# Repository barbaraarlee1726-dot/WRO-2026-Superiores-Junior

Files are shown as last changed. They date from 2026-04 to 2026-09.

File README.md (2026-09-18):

WRO-2026-FUTURE ENGINEERS
---------------------------
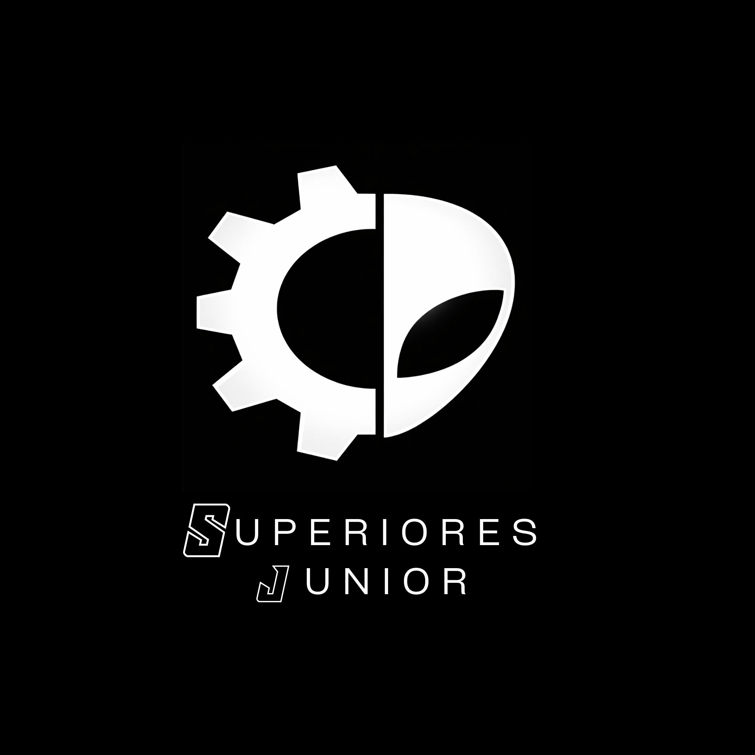
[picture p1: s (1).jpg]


This document describes the complete design and implementation of an autonomous vehicle built to compete in the World Robot Olympiad (WRO) 2026 under the Future Engineers category. Our robot integrates computer vision, gyroscopic navigation, ultrasonic sensing, and custom PCB design to achieve reliable autonomous operation.
The WRO Future Engineers category challenges teams to design a vehicle capable of operating without any human intervention, adapting dynamically to track conditions and obstacles. The competition is divided into two main challenges: Open Challenge and Obstacle Challenge.

--------------

We are the Junior Superiors team, and we are one of the teams that will be participating in the 2026 WRO (World Robot Olympiad) Future Engineers category.

What is the WRO?

The WRO is a competition that, as its name suggests, is a global competition. We are participating in the Future Engineers category, which focuses on autonomous cars. We have developed our robot named Timmy, an autonomous car whose goal is to navigate two different tracks presented in the competition: the Open Challenge and the Obstacle Challenge. The Open Challenge is an open track without obstacles that we must complete in the shortest time possible; the faster we go, the more points we earn. The Obstacle Challenge uses the same track but with different obstacles. In the Obstacle Challenge, there are two pillars of two different colors that we must navigate without colliding with them; the red pillar means turning right, while the green pillar means turning left. Timmy must navigate all these obstacles without hitting the walls or pillars.

Our robot was designed as a single-piece unit; we did this to minimize the number of parts and make it simple to build. Since the robot is a single piece, it uses a traction system to support the robot’s entire weight because, being very large, it is quite heavy, which makes it difficult to reach high speeds. To solve this problem, we integrated a traction system so that with a single motor we can achieve a decent speed. We use a parallel steering system; its main advantages are saving space, having a greater advantage in turns because it provides better handling at high speeds, and reducing lateral wheel slip.
This is the process of building our robot, and here’s how it went: We started building the robot’s first base on the very first day. Since it was the first day, we were only able to build a small base for both the front and rear wheels; with the limited time we had that day, we only managed to build that small base, which  would serve as a reference for the entire robot. From there, we began experimenting; for example, the next thing we built was the steering mechanism with a design that was easy to turn,  or the servomotor, which was placed on the bottom to save space. We installed a steering system so that, with a single motor, the steering and the other motors could operate simultaneously. Then we expanded the robot a bit to make more room for the next components. Since the top was a bit uneven, we created a platform where we could work more easily. We reinforced all the components, added ultrasonic sensors to the sides of the robot to modify them later, created the platform for the HuskyLens, and mounted the board, then reinforced everything again with screws. You can review everything we just mentioned in the blog, journal (in the “Others” section), and in the documentation section.

The code we use is actually quite simple: we program the Husky Leens camera using Arduino via the PCB. The camera detects the colors of the pillars for the Obstacle Challenge category; if HuskyLeens detects a red pillar, it turns right; if it detects a green pillar, it turns left; so our robot knows which way to turn. The ultrasonic sensors are used for both categories (Open Challenge and Obstacle Challenge); they detect the black walls, so when they detect them at a certain close distance, the robot will turn to avoid colliding. We programmed everything using the board and an Arduino Uno; you can check out the code in src.

Initial tests: We started on the first OpenChallenge track, so our programming for it went something like this: we programmed the ultrasonic sensors so that at a specific distance, the robot would turn in the opposite direction.  in the first tests we got decent results; the robot veered off course a bit, but we calibrated it. It was slow, so we adjusted the speed and also the rotation so that the increased speed wouldn’t cause it to crash. We also had trouble calculating when to stop so that it would be on the exact line or remain in the parking spot. After some trial and error, we came up with a program that worked well for us, and all that was left was to improve it. However, when we did that, it started to malfunction a bit, so we calibrated both the components and the program to fix it. For the Obstacle Challenge, since it was already very late, we didn’t have time to create a highly efficient program, though it still turned out to be effective. The program was simple: if the HuskyLens detected the red pillar, it turned left; if it detected a green one, it turned left. Finally, we reduced the speed and the turning radius so it wouldn’t collide with the pillars (you can review the entire program in the src section).

The components we use for our robot (Timmy) are essential because they essentially serve as the robot’s legs and eyes. Our chassis design creates adequate spaces for each component so that they complement one another. The EV3 motor (located at the bottom) provides power and saves space thanks to the strategic positioning of each component. Additionally, on the bottom, aside from the motor, is the traction system designed to boost the wheels’ speed, in addition to another system we have for the wheels. Finally, also on the bottom is the steering system, which, as we’ve already mentioned, is effective and precise. Moving to the top of the robot, we have the actual electronic components. To start with, there is the heart of Timmy, the PCB, which essentially handles all the programming—including that of the motor and steering—at the same time, despite being a LEGO build. on either side of the board are several ultrasonic sensors that help prevent collisions with walls. The HuskyLens camera with the AI system is very useful since it saves us a lot of programming work and detects the different pillars very well. Our main problem was all the dead space we left due to a construction issue—the top wasn’t very level, so we added several pieces to make it somewhat flat and improve maneuverability. All that dead space we left meant we lost the space we were trying to save (dead space is unused space).

In conclusion, our robot features a stable, durable, and powerful design, capable of meeting the challenges it faces. It uses simple yet effective programming. In my opinion, our main goal is to inspire new people interested in robotics so they can have a good time while discovering new things.

Category: Future Engineers

Team Name: Superiores Junior

Location: Nuevo León, México

## TEAM PHOTO
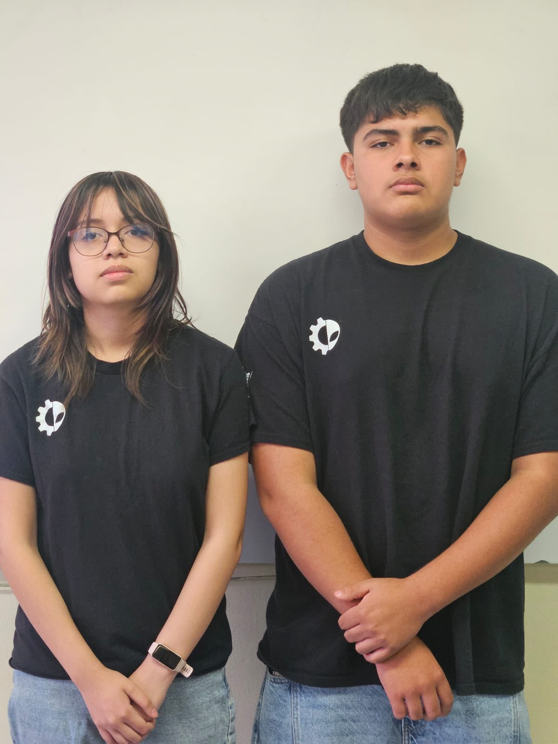
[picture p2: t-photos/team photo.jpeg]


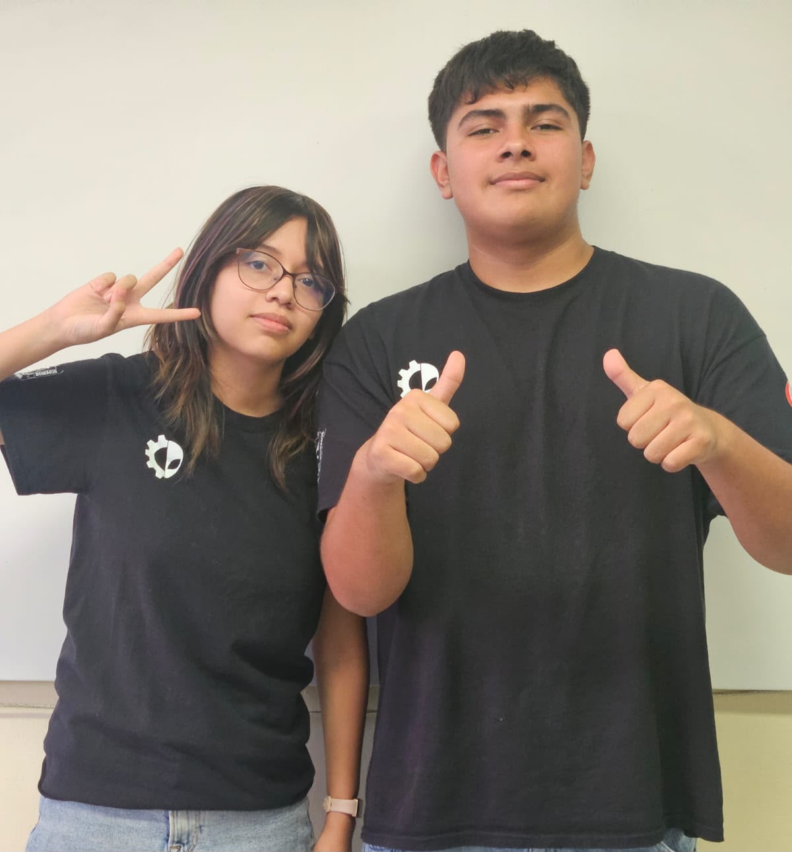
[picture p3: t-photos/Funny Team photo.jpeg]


TEAM MEMBERS
---------
Leadership & Coaching
Coach: Eduardo Alvarado González (40 years old)

<div align="center">
Eduardo Gonzalez
</div>

Role: Strategic Mentor and Founder. 
Eduardo is an engineer and professor who founded "Los Grises Superiores" in 2014. His vision has guided multiple generations of students to succeed in national and international robotics competitions, building a culture of technical excellence, teamwork, and resilience. He provides strategic direction and ensures all engineering decisions align with competition requirements.

---------------------------

Bárbara Arlee Flores Marroquín (15 years old)

Role: Captain and Electronics Lead.

Age:15

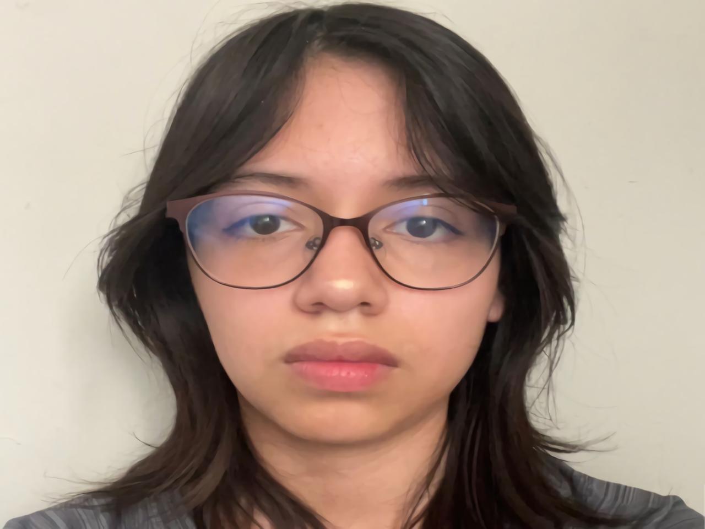
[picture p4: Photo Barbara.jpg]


"I got started in robotics in my sophomore year of high school, having been selected for my strong academic performance and adaptability, as well as my interest in challenges and complex designs, and I received a diploma for my achievements.I have honed my skills by taking additional robotics courses at this institution, where, in addition to learning, I received a certificate of completion."

Bárbara joined robotics in her sophomore year of high school, having been selected for her strong academic performance and interest in complex engineering challenges. She earned a diploma for her achievements and has since completed additional robotics certifications. In this project, she is responsible for electronic design, PCB development, and system integration.

---------------------------

Arath Alejandro Reyna Granados

Age:15

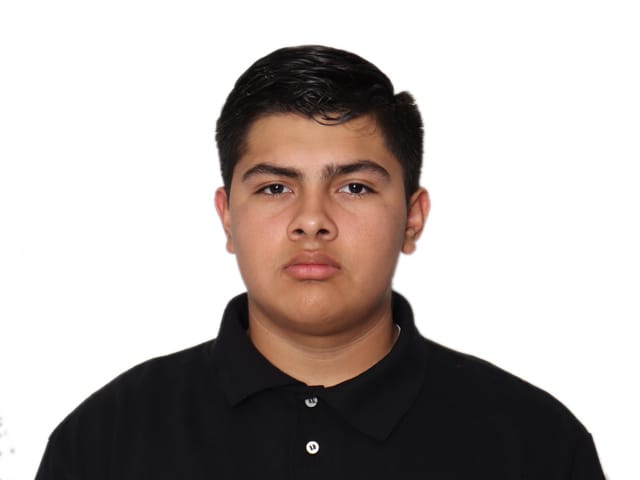
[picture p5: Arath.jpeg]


Role:Lead Programmer.

"I started in robotics at age 13 thanks to my mom, who started a robotics course at my school. There, I was told about a summer course offered by the Normal Superior of Nuevo León, Mexico, where I learned many things. After the course ended, a few months passed, and we were invited back. I was selected to compete in WRO."

Arath began his robotics journey at age 13 after participating in a course at the Normal Superior de Nuevo León, Mexico. He was subsequently selected to compete in WRO due to his aptitude and dedication. He is responsible for all firmware development, including the navigation algorithms, sensor fusion logic, and obstacle avoidance routines implemented on the Arduino Nano.

---------------------------

## 📚 Contents
- [Project Overview](#project-overview)
- [Vehicle Photos](#vehicle-photos)
- [Components and Hardware](#components-and-hardware)
- [Mobility Management](#mobility-management)
  - [Chassis](#chassis)
  - [Steering System](#steering-system)
- [Documentation](#Documentation)
- [Power and Sense Management](#power-and-sense-management)
  - [Power Management](#power-management)
  - [Sense Management](#sense-management)
- [Obstacle Management](#obstacle-management)
- [WRO 2026 Competition Info](#wro-2026-competition-info)
  
## Project overview

This document describes the design and implementation of an autonomous vehicle built to compete in the World Robot Olympiad 2026, under the category known as Future Engineers. This competition requires teams to conceive, assemble, and program a vehicle capable of operating without human intervention, adapting to different environmental conditions and established rules.
The Future Engineers category is divided into two challenges:

Open Challenge:

The vehicle must complete exactly three laps on a fixed-layout track. The direction of travel (clockwise or counterclockwise) and the starting position are determined randomly at the start of each run. This requires a navigation system that relies entirely on real-time sensor data rather than pre-programmed routes. Our system uses two HC-SR04 ultrasonic sensors to measure wall distances and an MPU6050 gyroscope to count rotations and determine lap completion.

Obstacle Challenge:

The Obstacle Challenge follows the same lap dynamics as the Open Challenge but adds colored pillars that act as traffic signals. The robot must detect and respond to each pillar in real time:

•	Red pillar → the vehicle must pass to the right of the obstacle

•	Green pillar → the vehicle must pass to the left of the obstacle

The HuskyLens AI camera handles color recognition and calculates the X-position of each detected object, allowing the servo steering system to compute the correct avoidance trajectory dynamically.

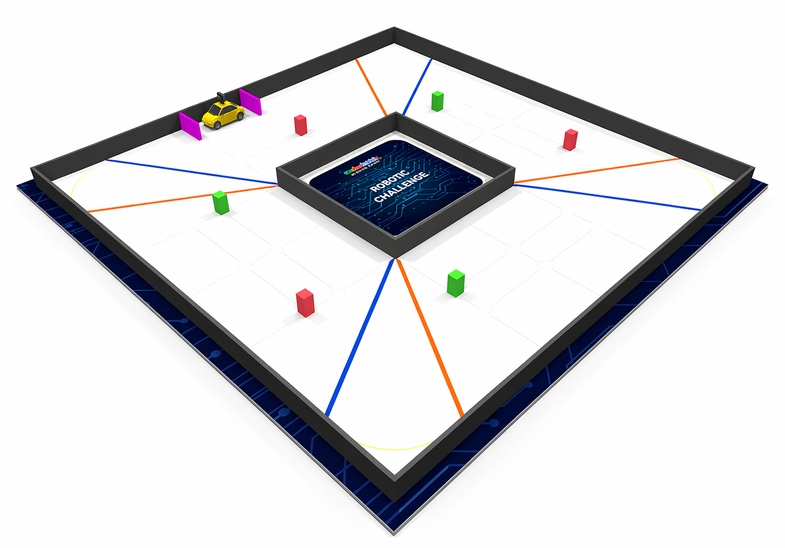
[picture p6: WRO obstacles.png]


# Vehicle Photos

<div align="center">

| Front | Back |
|:--:|:--:|
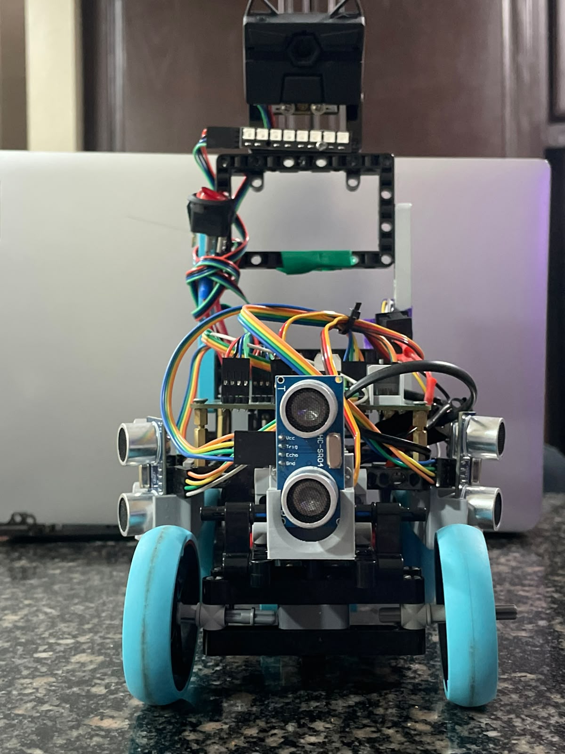
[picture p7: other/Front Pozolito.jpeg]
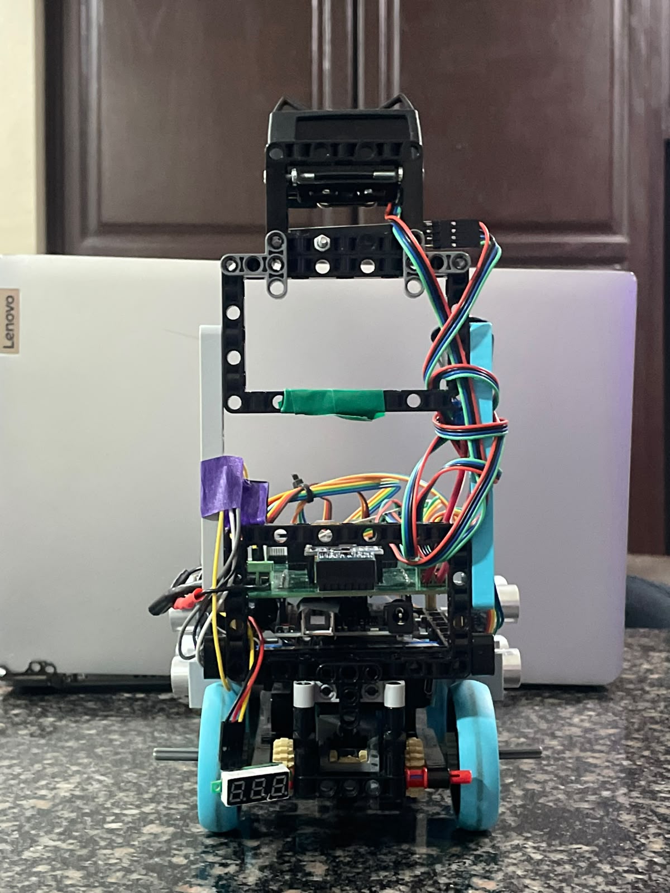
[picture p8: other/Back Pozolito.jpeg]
|  | |

| Bottom | Top |
|:--:|:--:|
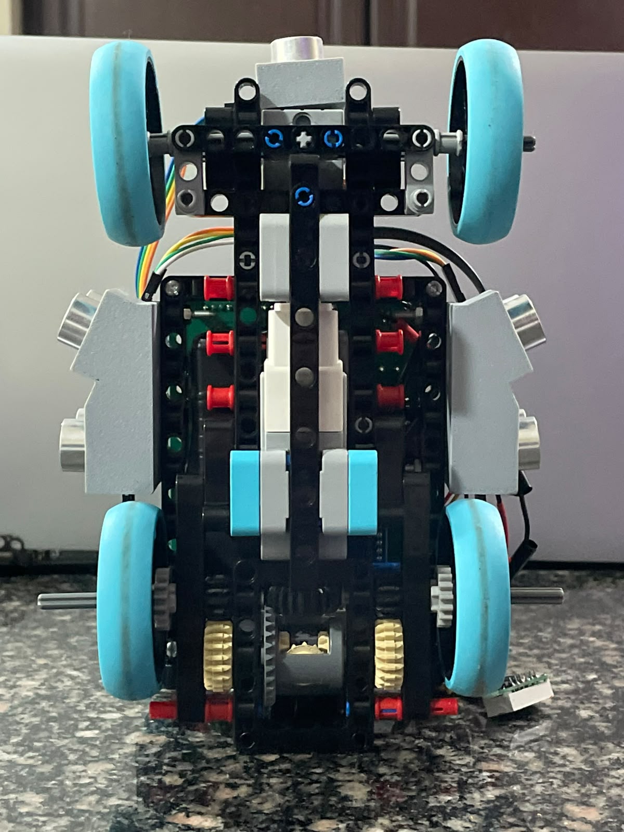
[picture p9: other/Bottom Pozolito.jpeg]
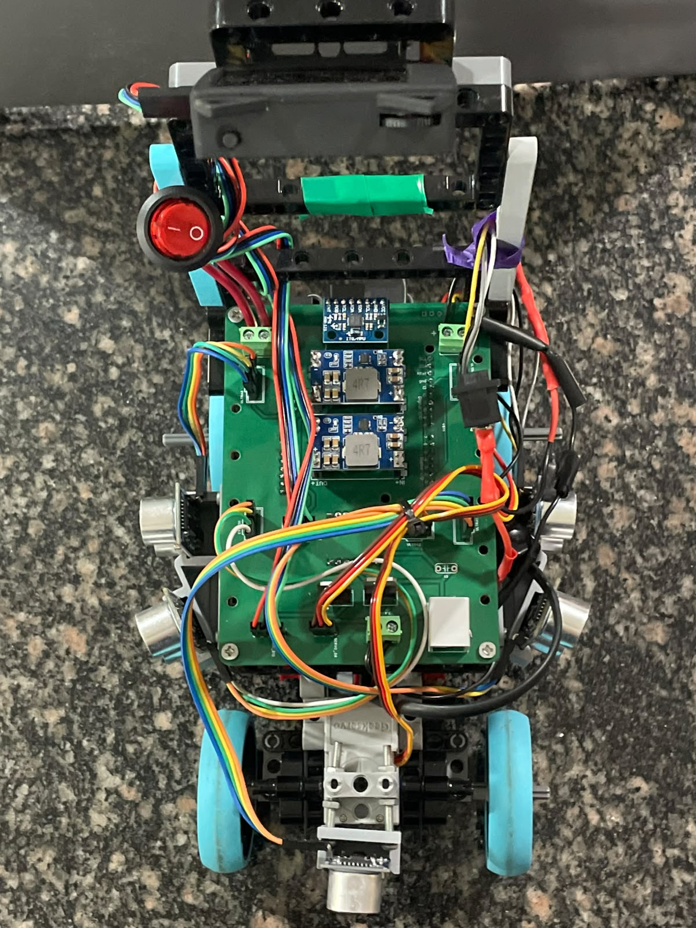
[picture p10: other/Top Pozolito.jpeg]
|  |    |

| Left | Right |
|:--:|:--:|
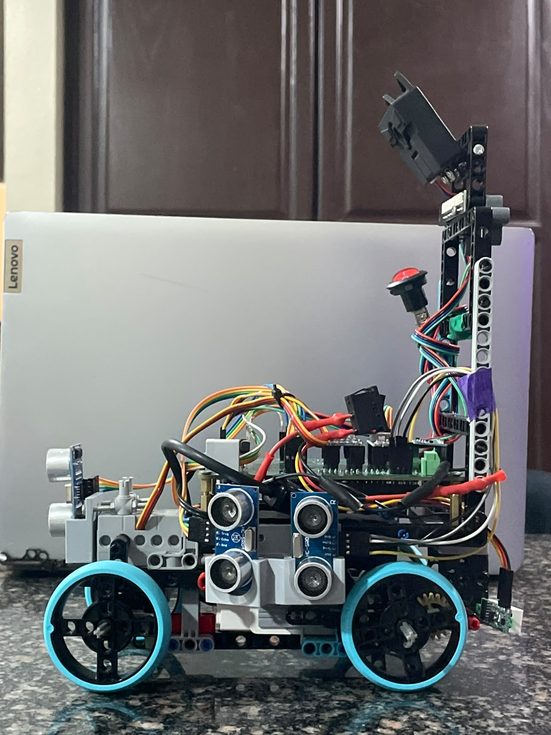
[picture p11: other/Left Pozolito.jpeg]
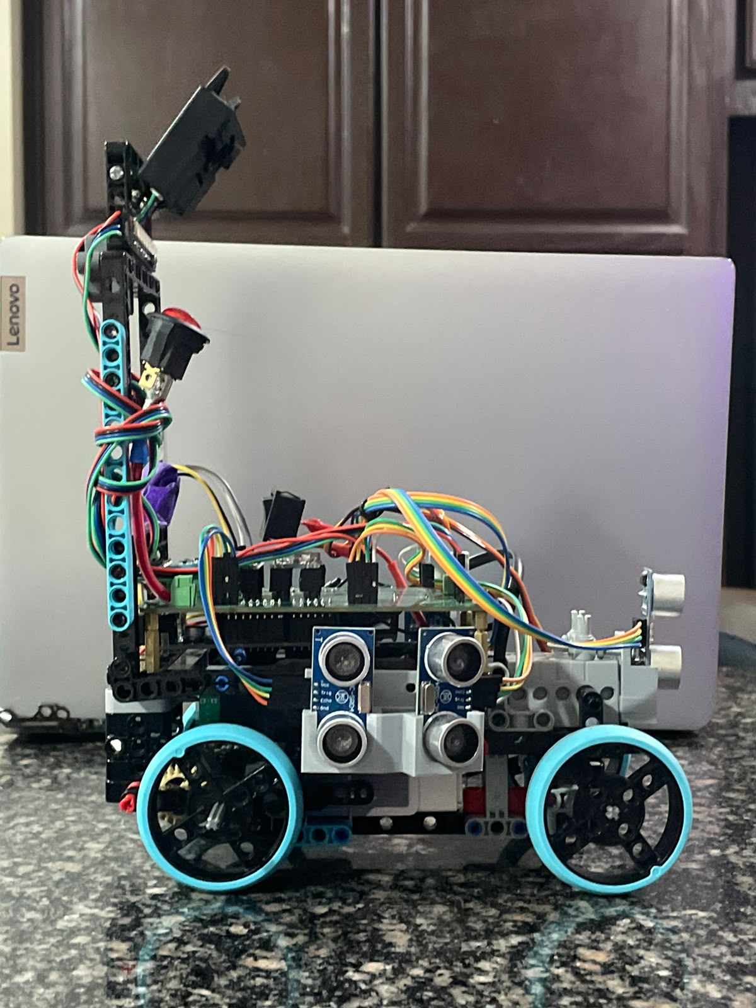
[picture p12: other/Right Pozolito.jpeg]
|   | |

## Components and Hardware

|COMPONENT| DESCRIPTION | IMAGE | PURCHASE LINK|
|---|---|---|---|
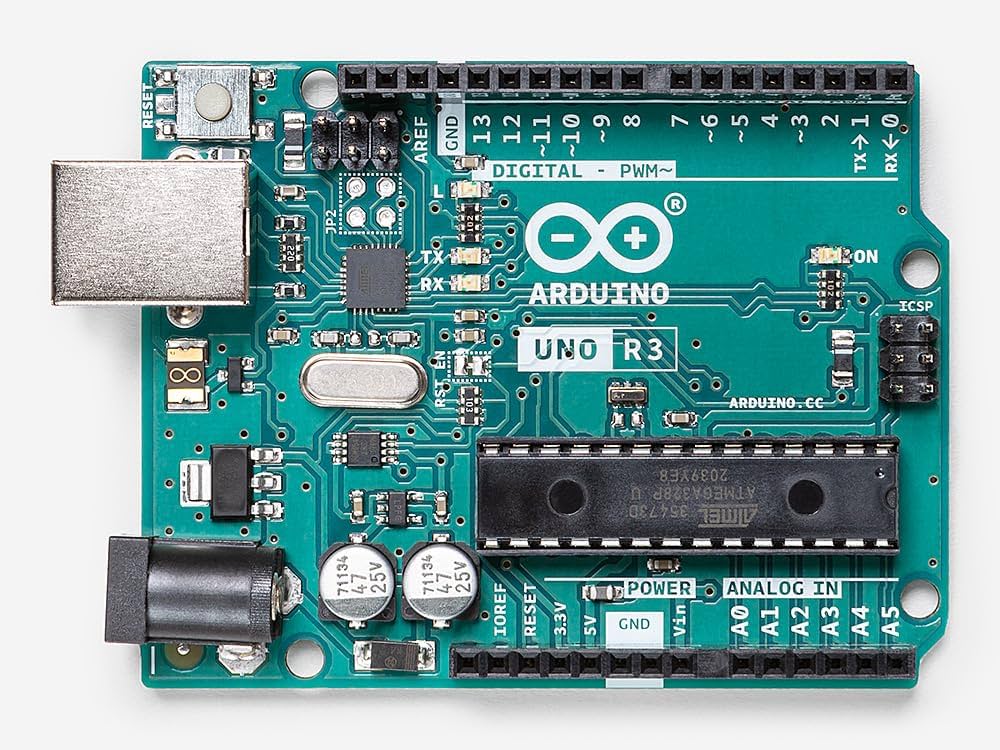
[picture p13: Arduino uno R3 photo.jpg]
|Arduino Uno R3|The Arduino Uno R3 is a development board based on the ATmega328P microcontroller, designed to centralize control of electronics and robotics projects. It features 14 digital input/output pins (six of which support PWM), six analog inputs, a 16 MHz processor, and USB connectivity for programming and power. It operates at an internal voltage of 5V and is widely used in educational and rapid prototyping environments due to its universal compatibility with thousands of sensors and expansion shields, as well as its direct integration with the free Arduino IDE software.|   |[Buy here](https://a.co/d/0gPOEQbD) |
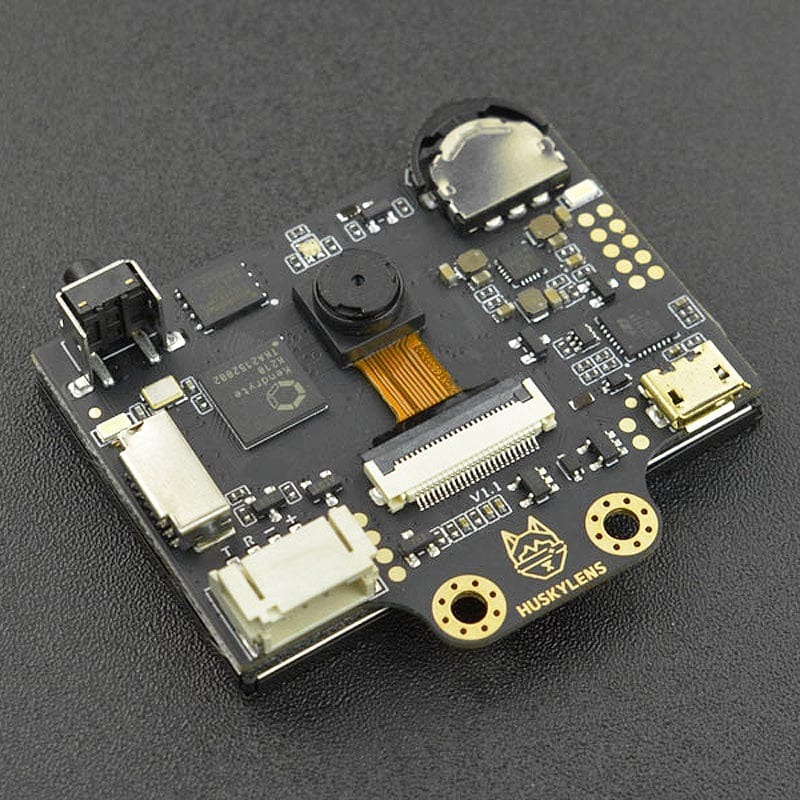
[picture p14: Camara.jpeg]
|HuskyLens DFRobot|Is an AI-powered machine vision sensor designed to detect faces, objects, lines, colors, and tags without complex algorithms.|  |[Buy here](https://www.dfrobot.com/huskylens/huskylens)|
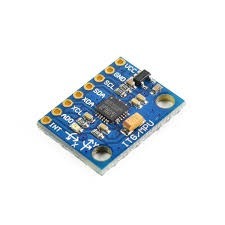
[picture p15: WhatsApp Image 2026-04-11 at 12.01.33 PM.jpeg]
|MPU6050| Is a 6-axis Motion Tracking device combining a 3-axis gyroscope and a 3-axis accelerometer on a single chip.Measures rotation angle (yaw) to count laps and trigger the stop sequence| |[Buy here](https://a.co/d/0gZv6Qfk)|
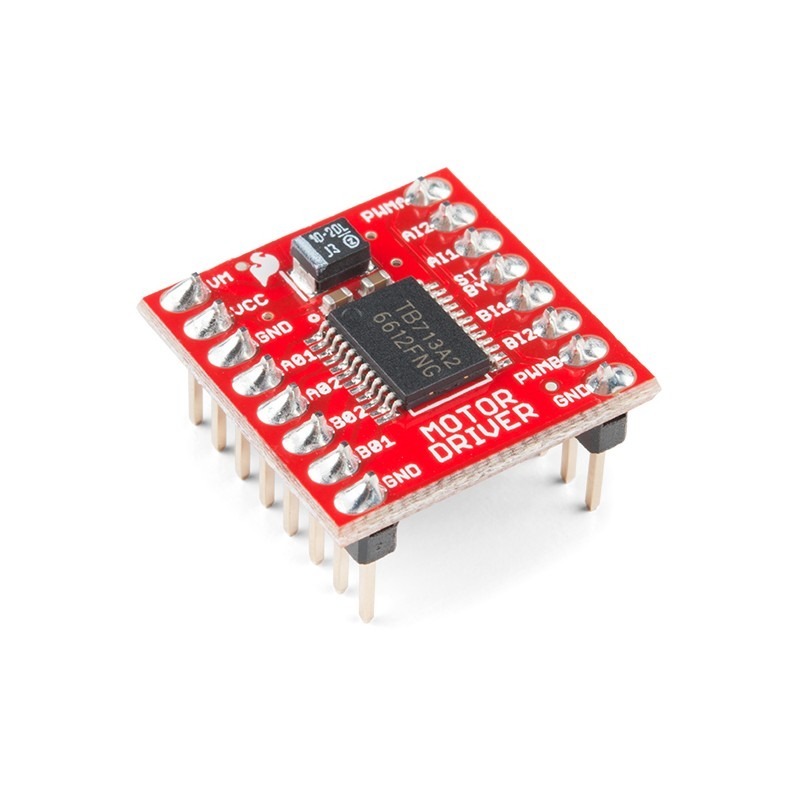
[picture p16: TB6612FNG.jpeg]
|TB6612FNG|Is a compact, high-efficiency dual H-bridge motor driver capable of independently controlling two DC motors, at 1.2A continuous current.Dual H-bridge motor driver, 1.2A continuous, 3A peak, 2.7–5.5V logic| |[Buy here](https://a.co/d/0eNh6qiz)|
|EV3 Motor|Are intelligent, tacho-feedback servos with built-in rotation sensors (1-degree resolution) for precise, Auto-ID control.9V DC, 260 rpm no-load, 8 N·cm stall torque, 1° tacho resolution|<div align="center">OpenMV Cam H7 Plus</div> |[Buy here](https://ebay.us/m/QtXLZA)|
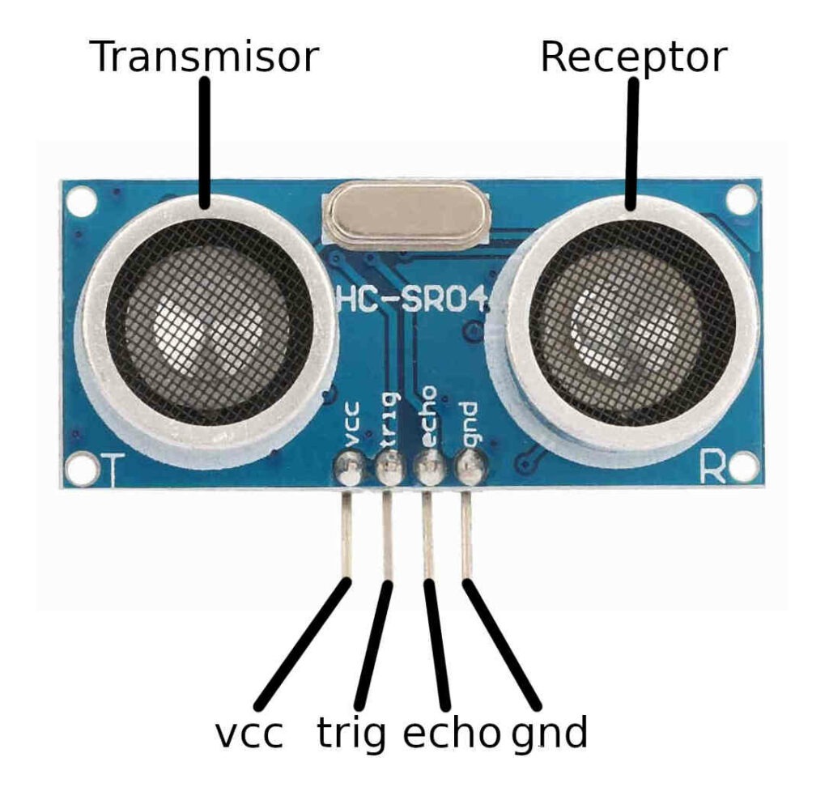
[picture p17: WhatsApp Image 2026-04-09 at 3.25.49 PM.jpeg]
|Ultrasonic Sensor|Is an ultrasonic distance sensor that uses sonar to determine the distance to an object.Measures left/right wall distances for lane-centering control| |[Buy here](https://www.steren.com.mx/sensor-ultrasonico.html)|
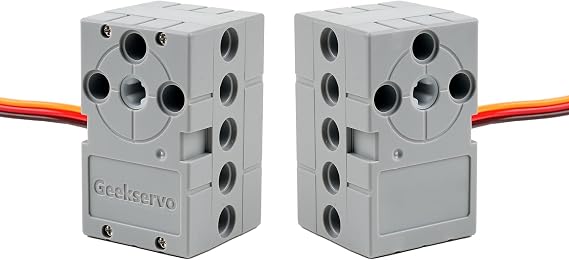
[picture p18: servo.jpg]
|Servomotor|The 2 kg Geekservo is a compact servo motor specifically designed to connect natively to Lego Technic-style building blocks thanks to its housing with standard holes and cross-shaped shafts. It operates within a voltage range of 3.3 V to 6 V (allowing it to be connected directly to an Arduino board) and delivers up to 2 kg/cm of torque to move mechanical parts with ease. Its 360-degree continuous rotation capability makes it an ideal actuator for driving wheels, pulleys, and gears in robotic assemblies without the need to fabricate additional adapters.| |[Buy here](https://a.co/d/0ew7FNMZ)|
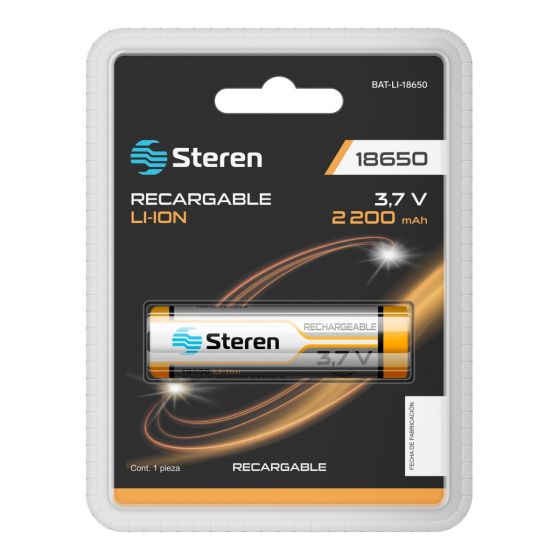
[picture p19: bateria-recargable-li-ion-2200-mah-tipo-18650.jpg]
|18650 Li-ion Rechargeable Battery 2200 mAh|Is a cylindrical rechargeable lithium-ion cell with a capacity of 2200 mAh, commonly used in portable electronics and power devices, measuring approximately 18 mm in diameter and 65 mm in length.| |[Buy here](https://www.steren.com.mx/bateria-recargable-li-ion-2200-mah-tipo-18650.html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)|
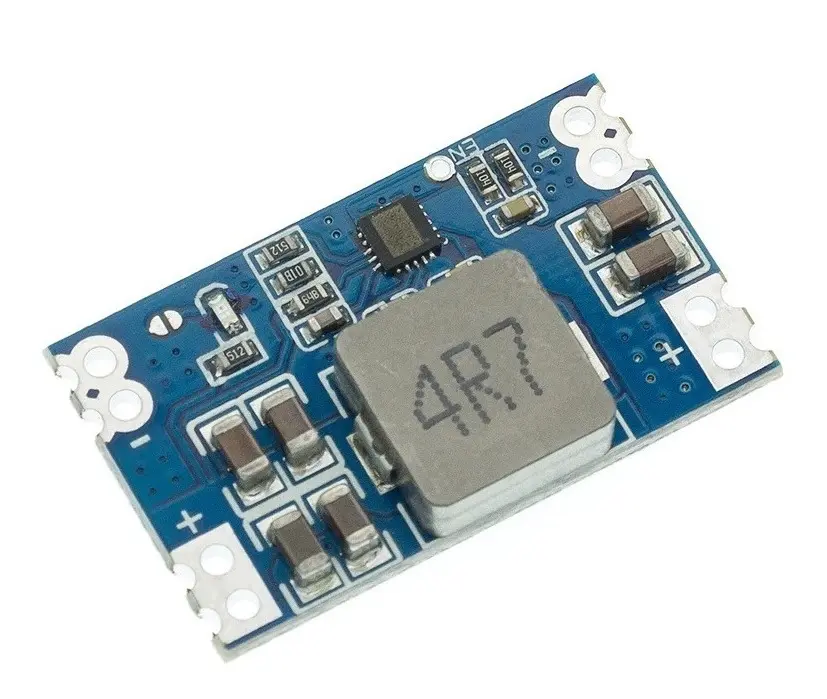
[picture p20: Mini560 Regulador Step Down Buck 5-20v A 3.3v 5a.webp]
|Mini560 Buck Step-Down Voltage Regulator 5–20V to 3.3V 5A|Is a compact DC-DC buck converter designed to step down an input voltage from 5–20V to a stable 3.3V output, supporting up to 5A of current, commonly used for powering microcontrollers and low-voltage electronic circuits.Steps down 7.4V to 5V for Arduino and sensors| |[Buy here](https://www.steren.com.mx/regulador-de-voltaje-positivo-5v-1a.html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)|
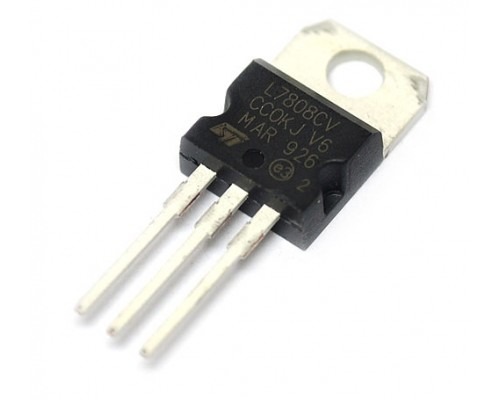
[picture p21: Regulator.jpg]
|5V/1A positive voltage regulator|Is a linear positive voltage regulator designed to provide a stable 5V output with up to 1A of current, commonly used in power supply circuits to regulate and maintain a constant voltage for electronic components.| |[Buy here](https://www.steren.com.mx/regulador-de-voltaje-positivo-5v-1a.html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)
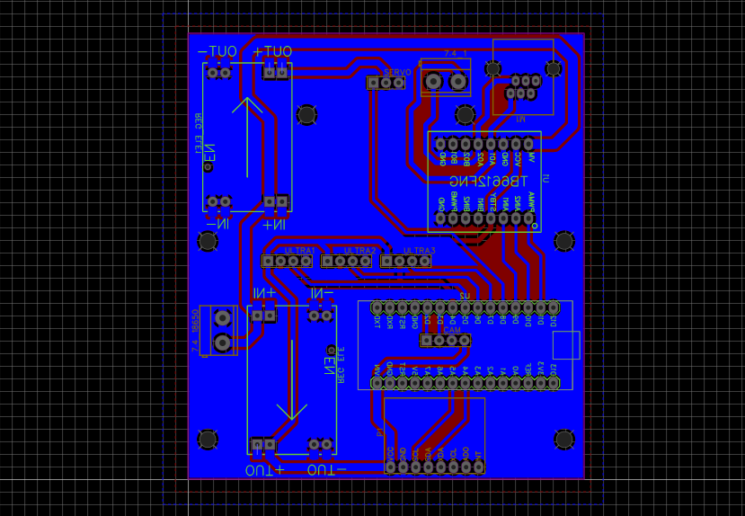
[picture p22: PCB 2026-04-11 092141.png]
|PCB|A PCB (Printed Circuit Board) is a flat board used to mechanically support and electrically connect electronic components through conductive pathways etched from copper sheets. It replaces loose wiring by providing organized connections between elements such as microcontrollers, sensors, regulators, and other electronic parts. PCBs improve the reliability, compactness, and stability of electronic systems, making them essential in robotics for integrating and managing circuits efficiently.|  |[Buy here](https://jlcpcb.com/)

<div align="left">

## Mobility Management

# Chassis
----
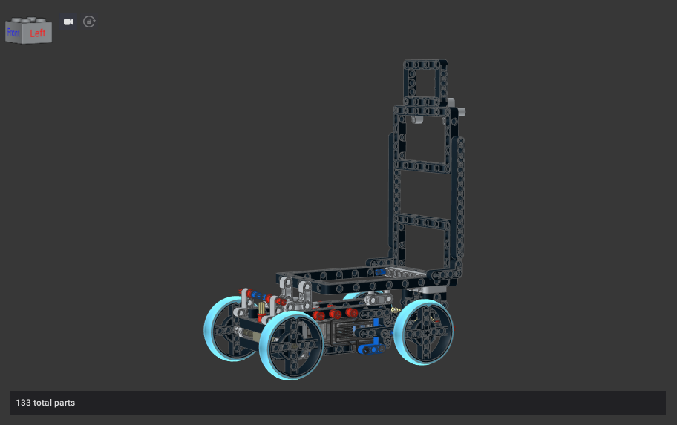
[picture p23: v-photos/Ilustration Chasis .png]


The chassis was designed and iterated through multiple prototypes, starting with a LEGO-based frame and evolving into a compact, rigid structure optimized for the competition track dimensions. The final design prioritizes a low center of gravity and tight turning radius to handle the track corners reliably.

### Steering System
The steering system uses a micro servo motor connected to pin D8 of the Arduino Nano. The servo operates within a constrained range of 65° to 115°, where 90° represents straight ahead. The steering angle is computed as a proportional correction based on the difference between left and right wall distances, or based on the X-position of a detected colored pillar.
The EV3 Medium Motor handles propulsion through a gear train, with the rear wheels driven by the motor output. A connecting rod links the front wheels for coordinated turning. The TB6612FNG motor driver controls motor direction via digital pins D9 and D10, with PWM speed control on pin D11.

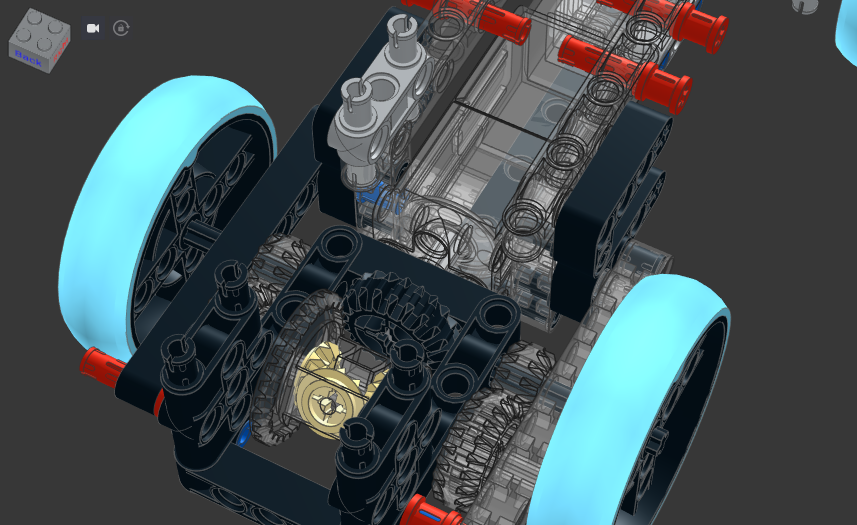
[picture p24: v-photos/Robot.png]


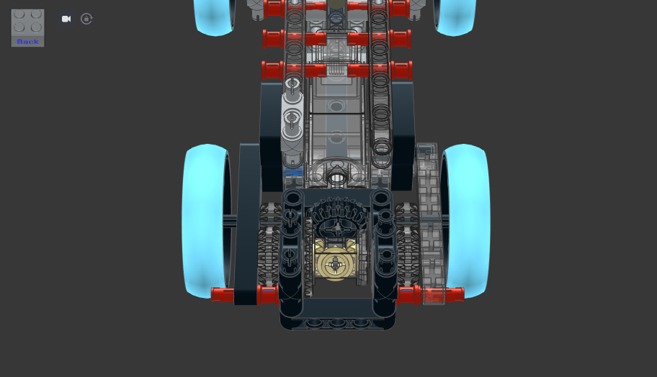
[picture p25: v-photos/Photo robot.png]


## Power and Sense Management
---
The Power and Sensor Management system of the vehicle is engineered to optimize energy distribution and ensure reliable operation of all electronic components. It carefully regulates the power supply to motors and sensors, maintaining stability and efficiency under varying load conditions. This system enables precise control over sensor readings and motor performance, supporting accurate navigation, obstacle detection, and overall vehicle functionality.

## Power Management
------------
The power system uses two 18650 Li-ion cells connected in series, providing a nominal 7.4V at 2200mAh capacity. This voltage is regulated down to 5V via a Mini560 Buck Converter (Step-Down DC-DC), which powers the Arduino Nano, the ultrasonic sensors, and the HuskyLens camera. The EV3 motor is driven directly by the TB6612FNG at the battery voltage level, with the STBY pin (D13) held HIGH to keep the driver active.

### Battery 18650


## Specifications:

<div align="center">

| Specification | Description |
|---|---|
| **Type** | Li-ion Rechargeable |
| **Model** | 18650 |
| **Nominal Voltage** | 3.7 V |
| **Capacity** | 2200 mAh |
| **Enclosure** | Metallic (for safety) |
| **Active Element** | Lithium-ion |
| **Dimensions** | 18 mm diameter × 65 mm length |

</div>

The 18650 Li-ion Rechargeable Battery is a cylindrical metallic-encased cell 
with a nominal voltage of 3.7V and a capacity of 2200 mAh, making it suitable 
for high-consumption electronic applications and robotics projects.

In this setup, we use two 18650 batteries connected in series to provide a 
combined output voltage of approximately 7.4V. This voltage is then regulated 
through a DC-DC buck converter to supply stable power to the Arduino Nano and 
the ultrasonic sensors, ensuring consistent operation throughout the run.

## Sense Management
------
The sensing system combines three complementary technologies to give the robot full awareness of its environment:

### Microcontroller (Arduino UNO R3)
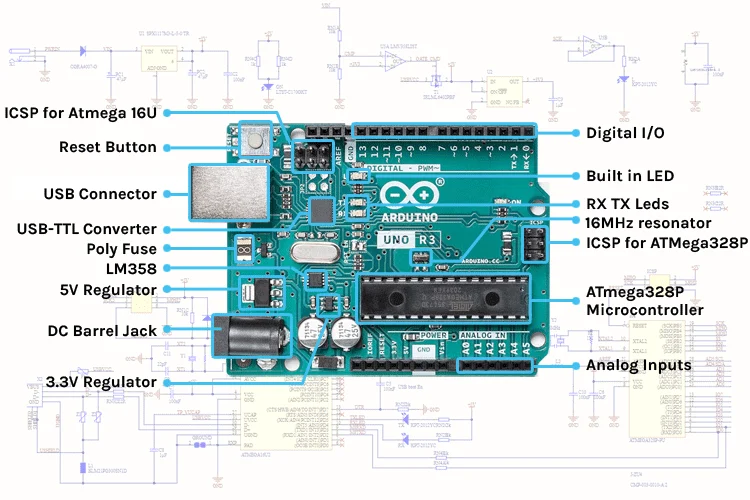
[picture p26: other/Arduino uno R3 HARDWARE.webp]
Arduino UNO R3


- Ultrasonic sensing (HC-SR04 x5): Five sensors provide distance readings around the robot (front, sides, and rear coverage), sharing two Trig lines (TRIG1, TRIG2) across the array, while each sensor has its own dedicated Echo pin (D2, D3, D5, D6, D7). Distance readings are taken during each control loop cycle and used to compute a wall-centering error signal for the servo, as well as to detect walls ahead before initiating a turn.

## Specifications:

<div align="center">

| Specification | Description |
|---|---|
| **Microcontroller** | ATmega328P |
| **Operating Voltage** | 5 V |
| **Input Voltage (recommended)** | 7–12 V |
| **Input Voltage (limit)** | 6–20 V |
| **Digital I/O Pins** | 14 (6 PWM outputs) |
| **Analog Input Pins** | 6 |
| **DC Current per I/O Pin** | 20 mA |
| **DC Current for 3.3V Pin** | 50 mA |
| **Flash Memory** | 32 KB (0.5 KB used by bootloader) |
| **SRAM** | 2 KB |
| **EEPROM** | 1 KB |
| **Clock Speed** | 16 MHz |
| **USB Connection** | USB-B |
| **Dimensions** | 68.6 mm x 53.4 mm |
| **Weight** | ~25 g |

</div>

The Arduino UNO R3 is a microcontroller board based on the ATmega328P, the same core chip used in the Nano, but on a larger form factor that offers more mechanical mounting stability and a standard USB-B connector for easier debugging on the workbench. It provides 14 digital I/O pins (6 with PWM) and 6 analog inputs, running at a 16 MHz clock speed.
It operates at 5V and can be powered through USB, a regulated 5V pin, or an external 7–12V input via its barrel jack or VIN pin.

We selected the UNO R3 over the Nano for the final version of the robot because the higher pin count and more robust I/O current handling (20 mA per pin vs. the Nano's tighter margins) gave us headroom to drive five ultrasonic sensors, the HuskyLens camera, the MPU6050 IMU, the steering servo, and a NeoPixel indicator strip simultaneously without signal degradation, while the larger footprint made it easier to mount securely to the chassis alongside the TB6612FNG driver board.

### Medium motor EV3
<div align="center">
EV3 Medium Motor
</div>

## Specifications

<div align="center">
  
| Specification | Description |
|---|---|
| **Model** | EV3 Medium Motor (45503) |
| **Type** | Servo Motor with integrated rotation sensor |
| **Operating Voltage** | 9 V DC |
| **Nominal Power** | 2.5 W |
| **No-load Speed** | ~260 rpm |
| **Stall Torque** | ~8 N·cm (0.08 N·m) |
| **Stall Current** | ~0.7 A |
| **Tacho Sensor Resolution** | 1° (360 counts per rotation) |
| **Weight** | 75 g |
| **Cable Length** | 25 cm |
| **Connector Type** | EV3 Plug |
| **Control Features** | Speed, position, and direction control | 

</div>

It operates at 9V DC and is designed to provide a balance between speed and torque, making it suitable for medium-load
We connect these motors directly to the EV3, and control them directly with the programming block for these motors, which in our robot consumes the following:

EV3 Brick controls all motors. Powered by 10V 2050 mAh battery.  
- **Movement motors (2):** 150–250 mA  
- **Steering motor (1):** 120–250 mA
  
In terms of power consumption, the motor typically draws around 250–300 mA under normal load, but this can increase up to 1.2 A when operating under heavy load or stall conditions. Its power output reaches approximately 2.5 W, depending on the applied voltage and load.

## Mini 560 Regulador Step down 

<div align="center">
Mini 560 module
</div>

**Specifications**

| Specification | Description |
|---|---|
| **Model** | Mini 560 DC-DC Step-Down Converter |
| **Input Voltage (Vin)** | 4.5V – 28V DC |
| **Output Voltage (Vout)** | Adjustable from 0.8V – 20V DC |
| **Default Output (pre-set)** | 5V (depending on module version) |
| **Output Current (Iout)** | Up to 3A (recommended continuous current: 2A for stability) |
| **Efficiency** | Up to 95% (depending on voltage and load) |
| **Switching Frequency** | 1.5 MHz |
| **Voltage Ripple** | < 30 mV (typical) |
| **Load Regulation** | ±0.5% |
| **Conversion Type** | Step-Down (Buck) Converter |
| **Control IC** | MP2307 or similar synchronous rectifier chip |
| **Operating Temperature** | -40°C to +85°C |
| **Dimensions** | 22 mm x 17 mm x 4 mm |
| **Protection Features** | Short-circuit, over-temperature, and over-current protection |
| **Typical Applications** | Power supply for microcontrollers, sensors, cameras, LED strips, and communication modules |

The Mini 560 Step-Down Regulator is used to efficiently convert higher input voltages to lower, stable output voltages suitable for powering microcontrollers, sensors, and other electronic modules in the robot. Its compact design and high efficiency make it ideal for embedded and portable applications.

We use this module to regulate the voltage supplied to the two Arduino PCBs, stepping it down from 7V to 5V to ensure stable operation and optimal performance.

## Ultrasonic HC-SR04

<div align="center">

</div>

## Specifications:

<div align="center">

| **Parameter** | **Description** |
|---|---|
| **Operating Voltage** | 5V DC |
| **Operating Current** | 15 mA (typical) |
| **Frequency** | 40 kHz |
| **Max Range** | 400 cm (4 m) |
| **Min Range** | 2 cm |
| **Accuracy** | ±3 mm |
| **Measuring Angle** | < 15° |
| **Trigger Input Signal** | 10 µs TTL pulse |
| **Echo Output Signal** | TTL signal, proportional to distance |
| **Dimensions** | 45 mm x 20 mm x 15 mm |
| **Working Temperature** | -15°C to +70°C |

</div>

## HuskyLens DFRobot

•	Visual recognition (HuskyLens): Operating in Color Recognition mode over I2C, the HuskyLens detects trained color blobs (red = ID 1, green = ID 2) and reports the X-coordinate of the detected object center, mapped to a ±160 range relative to the frame center.
<div align="center">
OpenMV Cam H7 Plus
</div>

<div align="center">

|**Parametrer**|**Description**|
|---|---|
| **Operating Voltage** | 5V DC|
| **Operating Current** |230mA (Typical)|
| **Frequency** |400 kHz|
| **Max Range** |02.0m|
| **Min Range** |0.5m|
| **Accuracy** |30f/s
| **Measuring Angle** | 320x240|
| **Trigger Input Signal** |I2C or UART (serial)|
| **Echo Output Signal** |serial UART or I2C interface|
| **Dimensions** |52mm x 44.5mm|
| **Working Temperature** |36.4°C to 43.2°C|

</div>

--------------------
<div align="left">

## Software Architecture

### State Machine

The robot's control software is organized as a finite state machine (FSM), 
allowing each subsystem (ultrasonic wall-following, HuskyLens color detection, 
lap counting) to activate only when needed and preventing conflicting commands 
between systems.

<div align="center">

| State | Description |
|---|---|
| **START** | Powers on all subsystems. Sensors and the HuskyLens camera initialize in parallel with the board power-up sequence; the robot waits briefly to ensure stable readings before entering the main loop. |
| **WALL-FOLLOW** | Default driving state. Uses proportional control on the two HC-SR04 ultrasonic sensors (error = distance_right − distance_left) to keep the robot centered between walls. |
| **OBSTACLE DETECT** | Runs concurrently with WALL-FOLLOW. The HuskyLens continuously scans for red/green color blobs; when one is detected above a confidence/size threshold, the FSM transitions to OBSTACLE AVOID. |
| **OBSTACLE AVOID** | Vision data overrides wall-following. The steering correction is computed from the difference between the pillar's X-position and a target X-offset (right pass for red, left pass for green). |
| **LAP COUNT** | Runs in the background throughout the run, tracking full rotations to determine when the required number of laps has been completed. |
| **STOP** | Triggered once the lap count condition is met. Motor output is set to zero and steering returns to center. |

</div
------
Wiring Diagram / Electrical Connections

<div align="center">
  
```mermaid
graph TD
    BAT["2x 18650 Li-ion en serie<br/>7.4V, 2200mAh"] -->|VM, vía interruptor| TB["TB6612FNG<br/>(driver motor EV3)"]
    BAT -->|7.4V| BUCK1["Mini560 Buck #1 (U1)<br/>→ 5+ (riel principal)"]
    BAT -->|7.4V| BUCK2["Mini560 Buck #2 (U3)<br/>→ alimenta 7805s"]
 
    BUCK1 --> UNO["Arduino UNO R3"]
    BUCK1 --> ULTRAS["5x HC-SR04<br/>ULTRA1–ULTRA5"]
    BUCK1 --> VOLT["Voltímetro<br/>(monitorea VM/batería)"]
 
    BUCK2 --> REGSER["Regulador 7805<br/>(REG_SER) → SER_5+"]
    BUCK2 --> REGLED["Regulador 7805<br/>(REG_LED) → LEDS_5+"]
    REGSER --> SERVO["Servomotor dirección<br/>(D8)"]
    REGLED --> LEDS["Tira NeoPixel<br/>(D12)"]
 
    UNO -->|"Trig D4 → ULTRA1,2,3 | Trig D13 → ULTRA4,5"| ULTRAS
    ULTRAS -->|"Echo: D5,D6,D7,D2,D3 (confirmado)"| UNO
 
    UNO <-->|I2C: SCL/SDA compartido| MPU["MPU6050 (IMU)"]
    UNO <-->|I2C: SCL/SDA, mismo bus| HUSKY["HuskyLens (CAM)"]
 
    UNO -->|AIN1, AIN2, PWMA| TB
    UNO -->|STBY| TB
    TB -->|MA1 / MA2, vía conector RJ12| EV3["Motor EV3<br/>(tracción)"]
 
    style BAT fill:#fde68a
    style BUCK1 fill:#bbf7d0
    style BUCK2 fill:#bbf7d0
    style UNO fill:#bfdbfe
```

## Control Algorithm

Wall-following uses **simple proportional control**: the steering correction is 
calculated as `error × Kp`, where `error` is the difference between the left 
and right ultrasonic readings. We chose proportional-only control over full PID 
because it was the approach the team was most comfortable with and understood 
best, it was faster to implement given our development timeline, and it was 
sufficient for what the robot needed to accomplish given its function.

### Edge Case Handling

During development we identified and resolved several edge cases:

- **Inaccurate wall distance readings:** In early tests, the ultrasonic sensors 
  did not measure distances reliably, causing the robot to misjudge wall 
  proximity and collide. This was resolved by recalibrating sensor placement 
  and adjusting the distance thresholds used for the wall-following correction.

- **False color detection:** Due to the HuskyLens camera's mounting height, 
  it initially detected color blobs from the robot's own front-facing parts, 
  mistaking them for pillars. This was fixed by adjusting the camera's angle 
  and height so its field of view only captures the track ahead.

- **Contact with obstacles during avoidance:** In some runs, the robot would 
  graze or lightly collide with pillars while attempting to avoid them. This 
  required refining the avoidance trajectory — adjusting the target X-offset 
  and turning radius used in the OBSTACLE_AVOID state.

- **Wall contact/dragging during avoidance:** Even though the robot generally 
  detected and avoided walls correctly, there were cases where it clipped or 
  dragged along a wall instead of maintaining a clean distance. This was 
  addressed by adjusting the acceptable error margin in the wall-following 
  logic through iterative testing until the robot consistently maintained a 
  safe distance without contact.

### Testing & Tuning Process

The steering and speed parameters were tuned through iterative testing — 
around 6–7 test runs — measuring lap completion time after each adjustment. 
When a change showed improvement (faster, more stable laps), speed was 
incrementally increased alongside other refinements made across the 
programming, rather than tuning a single parameter in isolation.

--------------------
  
## Obstacle management

The obstacle avoidance algorithm prioritizes vision data over wall-following when a colored pillar is detected.
The obstacle avoidance system was designed in accordance with the competition rules: a **red pillar** indicates a right turn, while a **green pillar** indicates a left turn.  
To determine the correct avoidance side, the robot calculates the difference between the **detected X position** from the camera and a predefined **X target**.  
This approach ensures a reliable and consistent maneuver direction, improving the robot’s decision-making during navigation.
he vision system was also designed to support the obstacle avoidance logic.
For this purpose, the X-coordinate at the base of the detected blob was used as the main metric, providing more reliable results than using the object’s area, which occasionally produced inconsistent data.

------
## Systems Thinking & Engineering Decisions

### Subsystem Interaction

Pozolito's subsystems are designed to work together without conflict: the 
Arduino Nano acts as the central controller, reading the ultrasonic sensors 
and HuskyLens simultaneously, and outputting steering and motor commands 
through the TB6612FNG driver. Under normal conditions the ultrasonic sensors 
drive the steering correction (wall-following); when the HuskyLens detects a 
colored pillar, its data takes priority and overrides the wall-following 
correction until the obstacle is cleared, at which point control returns to 
the ultrasonic sensors. This handoff between vision and distance sensing is 
the core constraint the software architecture is built around.

### Engineering Decisions: Why X Instead of Y

**HuskyLens vs. a simple color sensor:** Our first approach used a basic 
color sensor to identify the red/green pillars. In testing, it proved 
inconsistent — detections were less precise and less repeatable across runs. 
We switched to the HuskyLens AI camera because it detected colors with 
noticeably higher precision and consistency, in addition to already 
providing the object's X-position, which our avoidance logic depends on.
  
### Risk Analysis & Mitigation

<div align="center">

| Risk | Cause | Mitigation |
|---|---|---|
| Robot failed to move (traction/servo not responding) | Programming error in the motor/servo control logic | Identified and corrected the code controlling the traction and steering output |
| Unreliable ultrasonic sensor readings | One sensor was incorrectly wired/connected | Inspected and corrected the wiring/connections to the ultrasonic sensors |

Identifying these failure points early in testing allowed the team to correct 
them before they affected performance in the actual runs, and reinforced the 
importance of verifying both code and physical connections whenever a 
subsystem behaves unexpectedly.

</div>
---
PCB
A custom PCB was designed in EasyEDA to consolidate all electronic components onto a single board, reducing wiring complexity and improving reliability. The board includes dedicated connectors for two ultrasonic sensors (ULTRA1, ULTRA2), the HuskyLens camera (CAM), the servo motor (SERVO), the EV3 motor outputs (+OUT / -OUT), the Arduino Nano (U2), the TB6612FNG driver (U1), and BEC voltage regulators for 5V and 3.3V rails. The shared Trig line for both ultrasonic sensors is routed directly on the PCB to minimize signal noise.
<div align="center">OpenMV Cam H7 Plus</div>

------
# Documentation

This is the process and documentation section during the WRO|Future Engineers event on building our autonomous robot

  Chasis prototype
 -
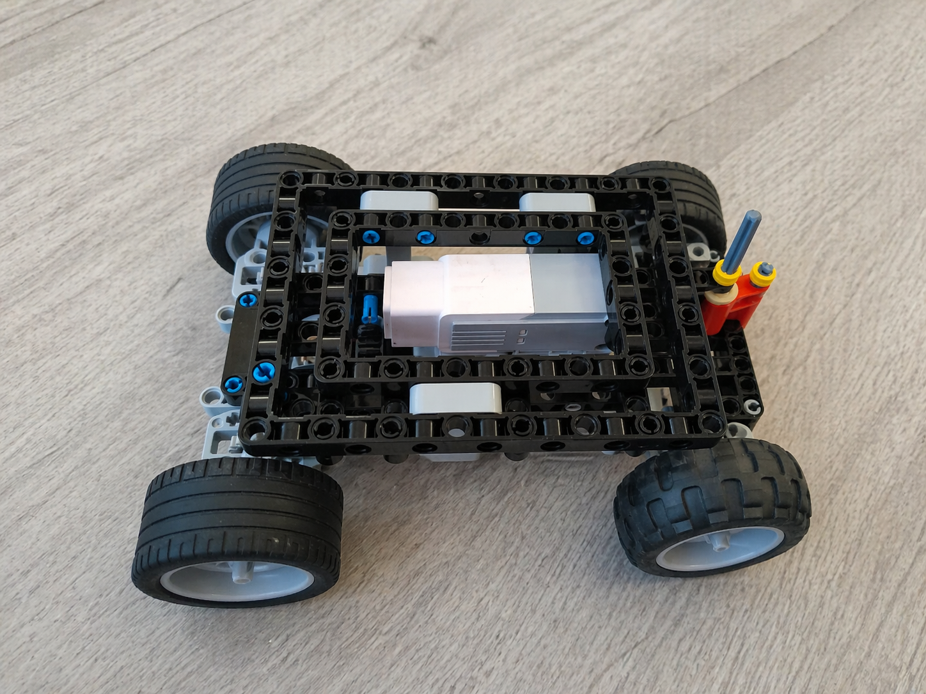
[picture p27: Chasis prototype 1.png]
  
  This was our first design of our lego chasis. The chasis is designed for a solid base, we mantained this design for the final design.

  Robot prototype
  -
  This is our first design robot, whith a little part of electronic components (ultrasonic sensor)The design has some electronic components but it´s still incomplet.
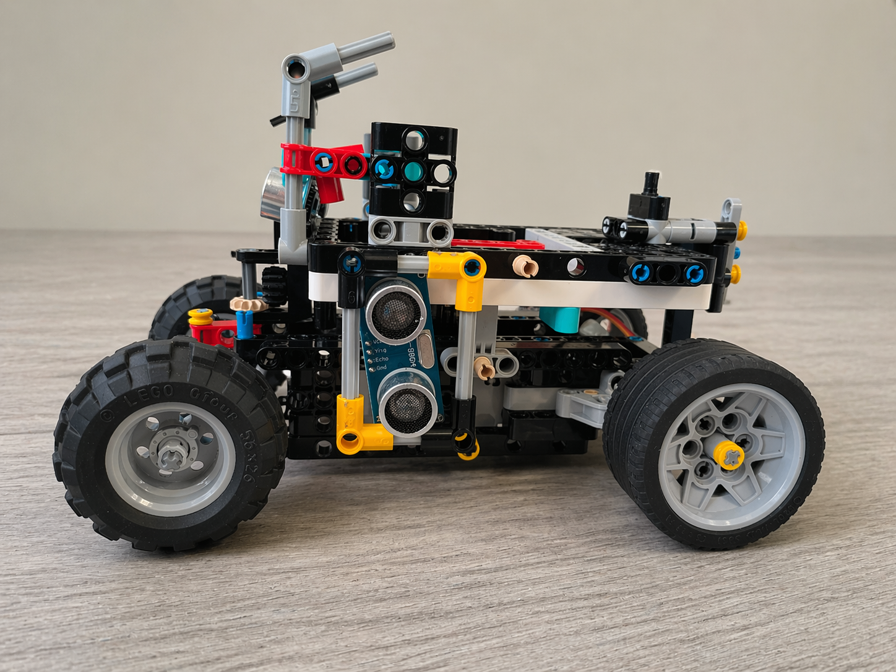
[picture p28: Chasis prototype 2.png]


Upgraded Design
-
This was our upgraded design for the WRO Future Engineers, this robot was used on WRO videos.
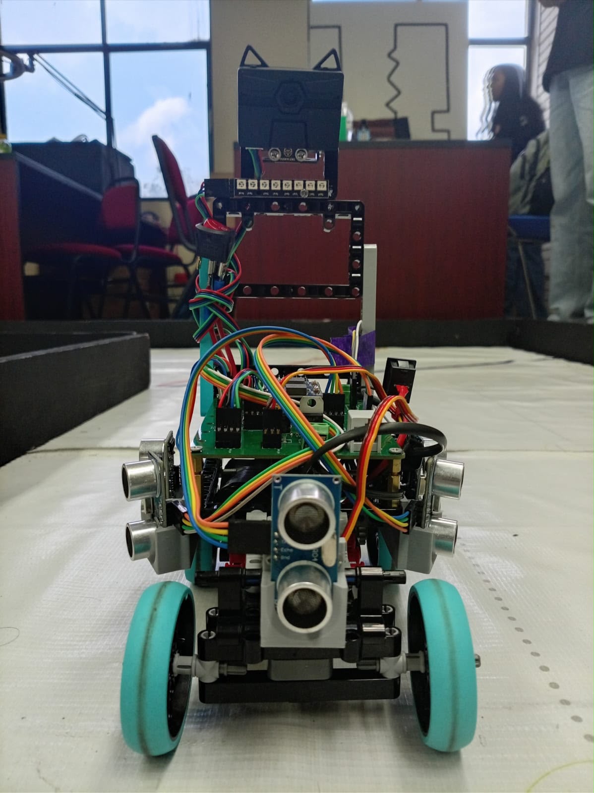
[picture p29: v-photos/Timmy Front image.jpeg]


 Final Design
------------------
  This is our final design, with ultrasonic sensors on left, right and front.
<div align="center">OpenMV Cam H7 Plus</div>

Video
------------

<div align="center">

  ### 🧩 Open Challenge  


### 🚧 Obstacle Challenge  


-------
## WRO 2026 Competition Info
----
<div align="left">
This robot was developed for the World Robot Olympiad 2026 Future Engineers category. The official competition rules (available in English and Spanish on the WRO website) define the track layout, obstacle placement, and scoring criteria. The vehicle must complete all three laps autonomously without any human intervention or remote control after the start signal.

[WRO 2026 RULES Future Engineers English](https://wro-association.org/wp-content/uploads/WRO-2025-Future-Engineers-Self-Driving-Cars-General-Rules.pdf)

[WRO 2026 RULES Future Engineers Spanish](https://drive.google.com/file/d/1IJEXWpP0N-TZuE2kj__HQJZUOQY-1Yf7/view?pli=1)

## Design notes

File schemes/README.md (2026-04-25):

Electromechanical diagrams
====

This directory contain several schematic diagrams in form of JPEG, PNG or PDF of the electromechanical components illustrating all the elements (electronic components and motors)

------
PCB
---
<div align="center">OpenMV Cam H7 Plus</div>

## HuskyLens DFRobot

<div align="center">
OpenMV Cam H7 Plus
</div>

<div align="center">

|**Parametrer**|**Description**|
|---|---|
| **Operating Voltage** | 5V DC|
| **Operating Current** |230mA (Typical)|
| **Frequency** |400 kHz|
| **Max Range** |02.0m|
| **Min Range** |0.5m|
| **Accuracy** |30f/s
| **Measuring Angle** | 320x240|
| **Trigger Input Signal** |I2C or UART (serial)|
| **Echo Output Signal** |serial UART or I2C interface|
| **Dimensions** |52mm x 44.5mm|
| **Working Temperature** |36.4°C to 43.2°C|

We conect the Husky DFRobot using screws in the legos piece to unite them, we conect them with the PCB and program it.

### Medium motor EV3
<div align="center">
EV3 Medium Motor
</div>

## Specifications

<div align="center">
  
| Specification | Description |
|---|---|
| **Model** | EV3 Medium Motor (45503) |
| **Type** | Servo Motor with integrated rotation sensor |
| **Operating Voltage** | 9 V DC |
| **Nominal Power** | 2.5 W |
| **No-load Speed** | ~260 rpm |
| **Stall Torque** | ~8 N·cm (0.08 N·m) |
| **Stall Current** | ~0.7 A |
| **Tacho Sensor Resolution** | 1° (360 counts per rotation) |
| **Weight** | 75 g |
| **Cable Length** | 25 cm |
| **Connector Type** | EV3 Plug |
| **Control Features** | Speed, position, and direction control | 

It operates at 9V DC and is designed to provide a balance between speed and torque, making it suitable for medium-load
We connect these motors directly to the EV3, and control them directly with the programming block for these motors, which in our robot consumes the following:

EV3 Brick controls all motors. Powered by 10V 2050 mAh battery.  
- **Movement motors (2):** 150–250 mA  
- **Steering motor (1):** 120–250 mA
  
In terms of power consumption, the motor typically draws around 250–300 mA under normal load, but this can increase up to 1.2 A when operating under heavy load or stall conditions. Its power output reaches approximately 2.5 W, depending on the applied voltage and load.

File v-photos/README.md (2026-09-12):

Vehicle's photos
====

This directory contain 6 diferent photos of our robot Timmy

<div align="center">

| Front | Back |
|:--:|:--:|
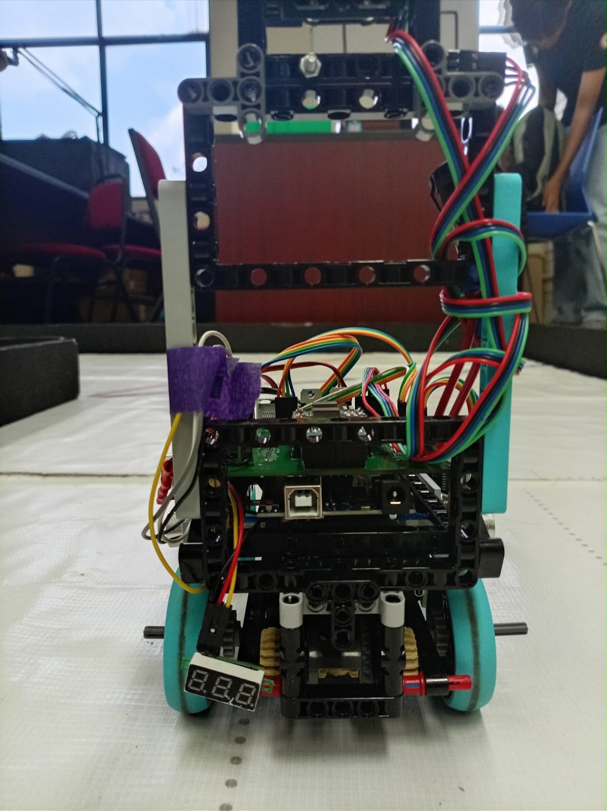
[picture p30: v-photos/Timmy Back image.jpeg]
|OpenMV Cam H7 Plus  | |

| Bottom | Top |
|:--:|:--:|
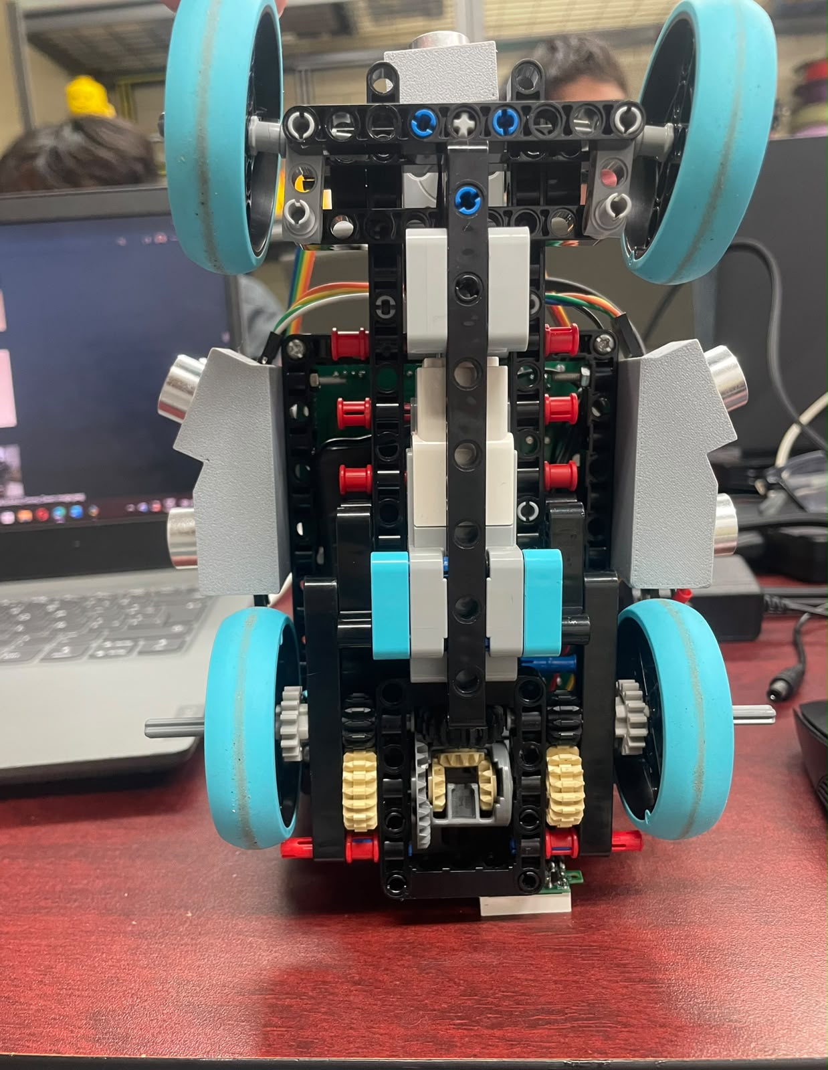
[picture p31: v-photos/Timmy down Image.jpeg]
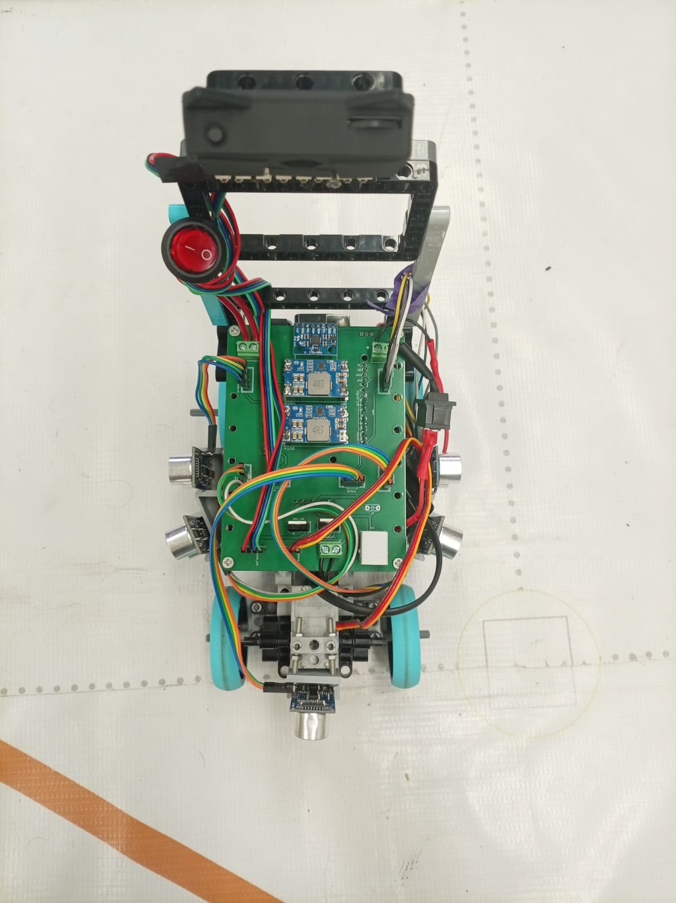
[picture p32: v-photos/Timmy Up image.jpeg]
|  |    |

| Left | Right |
|:--:|:--:|
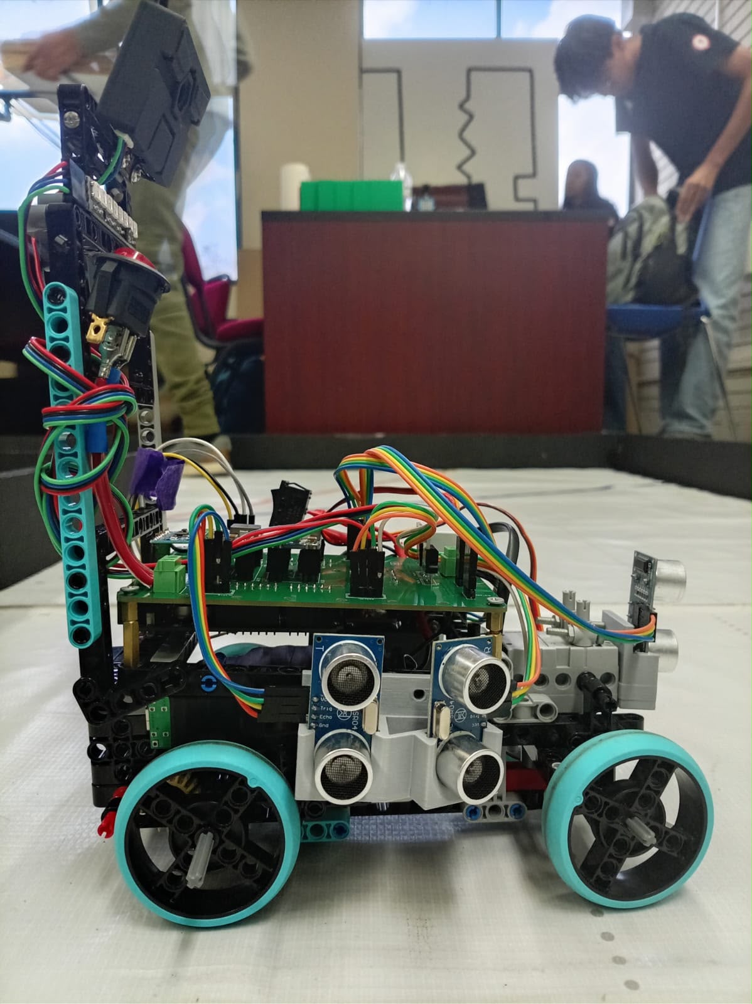
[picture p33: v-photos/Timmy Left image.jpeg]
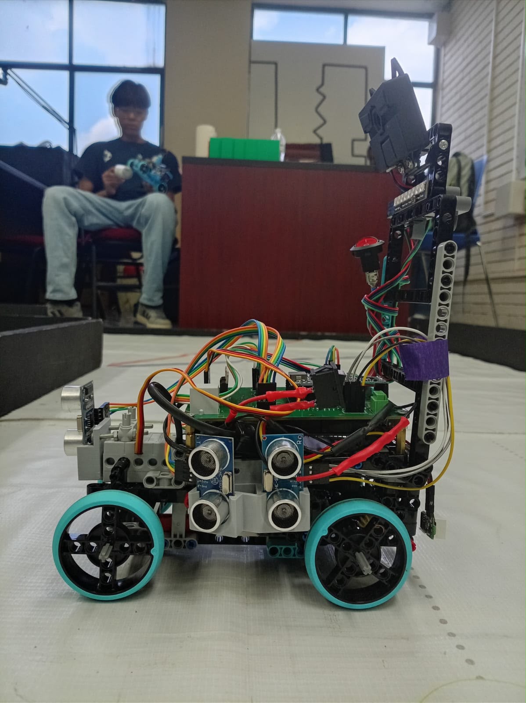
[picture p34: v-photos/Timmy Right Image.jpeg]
|   | |

---------
# Process
----
  
  Chasis prototype
 -
  <div align="center">OpenMV Cam H7 Plus</div>
  This was our first design of our lego chasis.

  Robot prototype
  -
  This is our first design robot, whith a little part of electronic components (ultrasonic sensor)
<div align="center">OpenMV Cam H7 Plus</div>

Upgraded Design
-
This was our upgraded design for the WRO Future Engineers, this robot was used on WRO videos.
OpenMV Cam H7 Plus</div>

<div align="center">

  Final Design
-
This is our final design, with ultrasonic sensors on left, right and front.
OpenMV Cam H7 Plus</div>

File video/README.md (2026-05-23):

Video
====

This are the videos of the two diferent challenges on WRO Future Engineers 2026
<div align="center">

  ### 🧩 Open Challenge  


### 🚧 Obstacle Challenge  


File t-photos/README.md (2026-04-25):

Team's photos
====

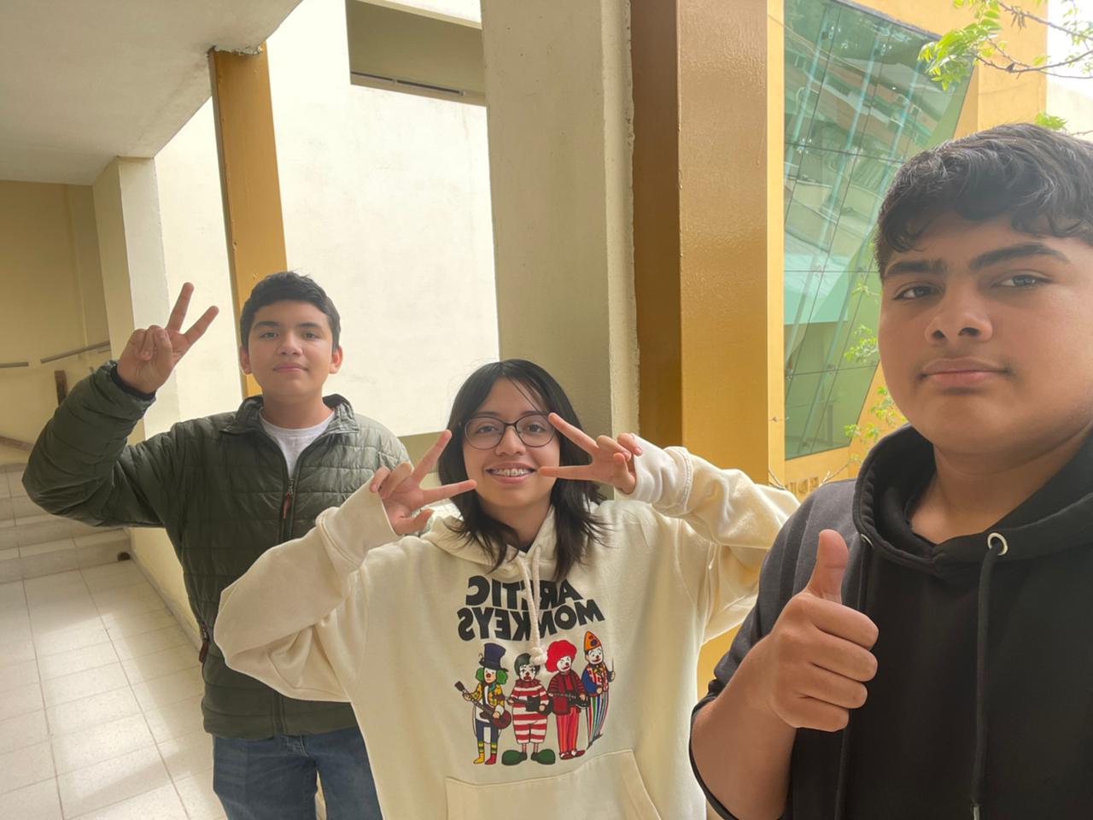
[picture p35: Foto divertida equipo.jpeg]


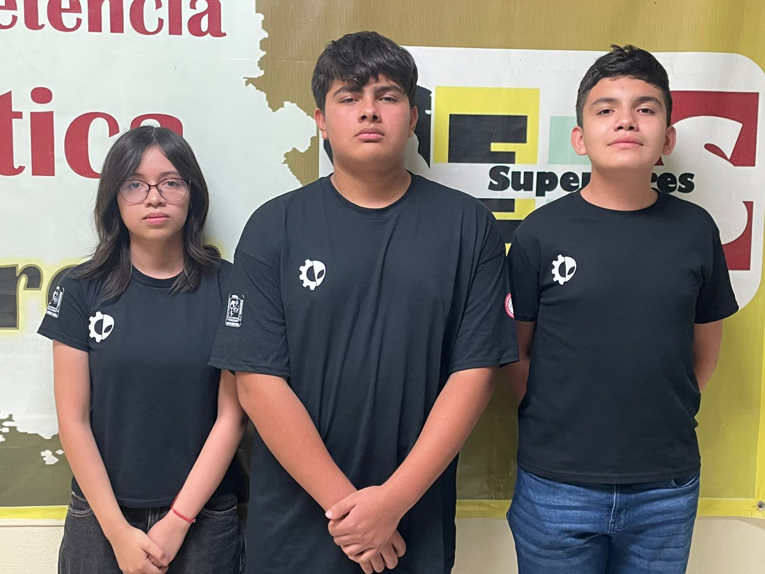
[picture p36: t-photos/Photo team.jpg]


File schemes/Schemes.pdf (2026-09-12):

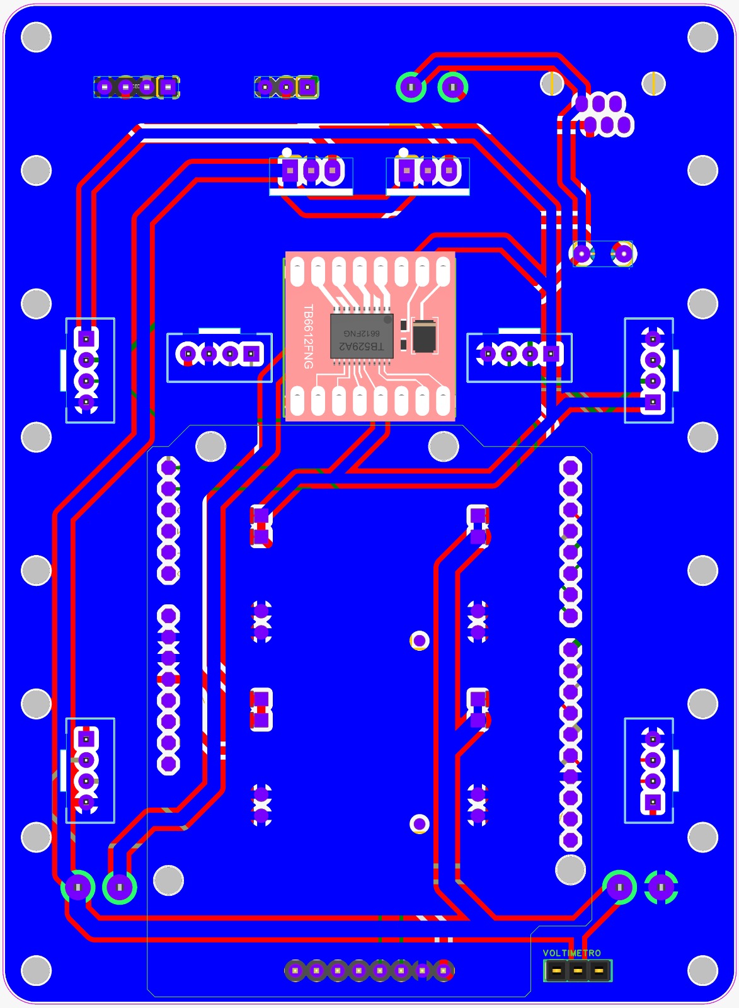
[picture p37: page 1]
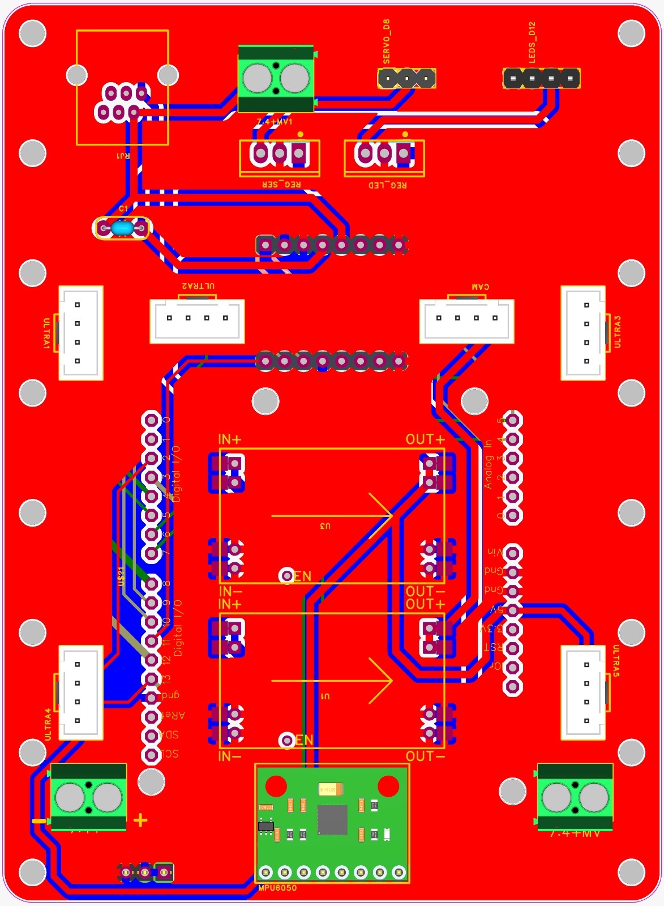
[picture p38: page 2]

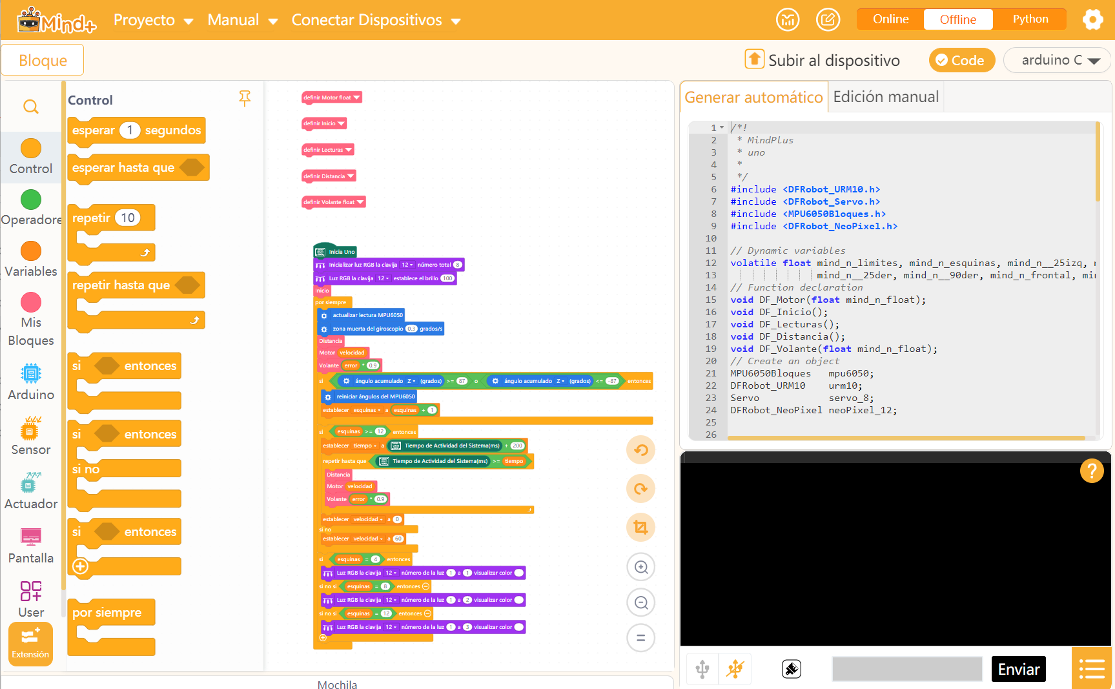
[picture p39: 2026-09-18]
src/Block Programming.png

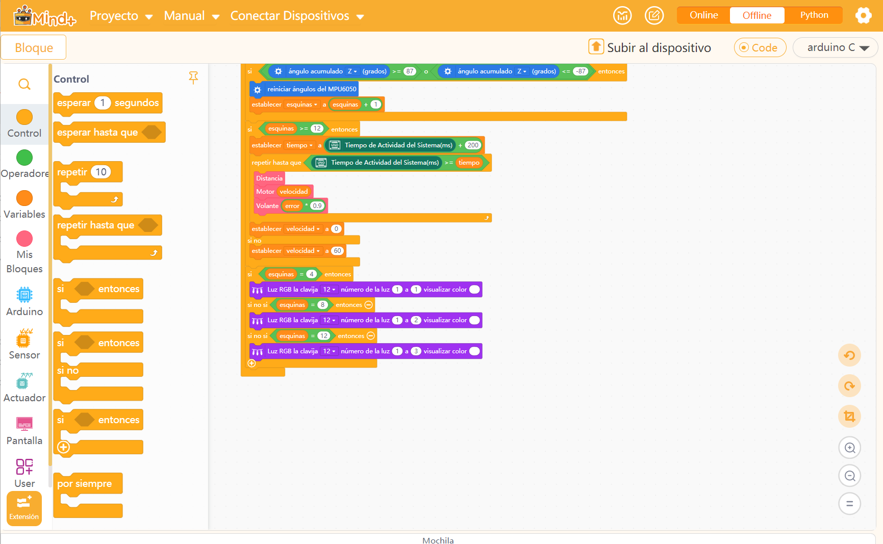
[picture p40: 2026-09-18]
src/WRO OPEN CHALLENGE BLOCKS 2.png

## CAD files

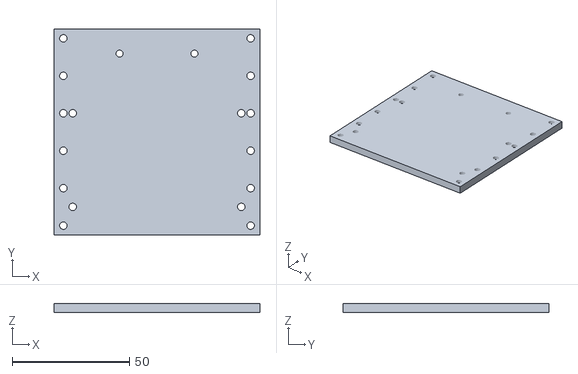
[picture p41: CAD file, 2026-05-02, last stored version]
models/3D model.stl
88.0 x 88.0 x 4.00

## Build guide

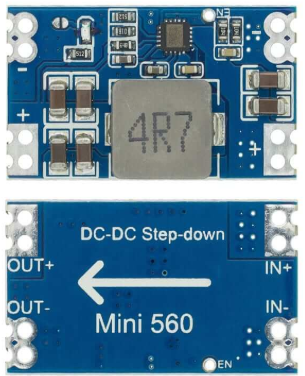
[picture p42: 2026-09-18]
other/Mini 560 Regulador Step down.png

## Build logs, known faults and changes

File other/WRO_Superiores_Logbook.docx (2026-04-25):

WORLD ROBOT OLYMPIAD 2026

Future Engineers Category

Technical Engineering Documentation

Team Name | Superiores Junior
Country/Region | México
Team Members | Arlee, Arath, Alexis
Coach | Eduardo Alvarado González
Age group | Future Engineers (14–22)
Season | WRO 2026
Repository GitHub | https://github.com/barbaraarlee1726-dot/WRO-2026-Superiores-Junior

Summary.

This document presents the technical engineering documentation for the Superiores Junior's autonomous vehicle developed for the WRO Future Engineers 2026 competition under the theme “Robots Meet Culture.” The report covers the mechanical design and chassis, the power and sensor architecture, the software strategy and obstacle avoidance logic, system-level engineering decisions, and reproducibility via the team’s GitHub repository. All design decisions are justified through iterative testing and data-driven trade-off analysis.

I. MOBILITY AND MECHANICAL DESIGN

We choose a medium EV3 motor, we implement a steering system for using only 1 motor to give more speed in all the robot, our design consists of a strong chassis, taking advantage of our height.

## A. Chassis Design

We chose a steering system for our robot, our robot takes advantage of the height, that´s why we use a steering system for a strong and fast robot. Our chassis is strong and resistance to support all the weight.

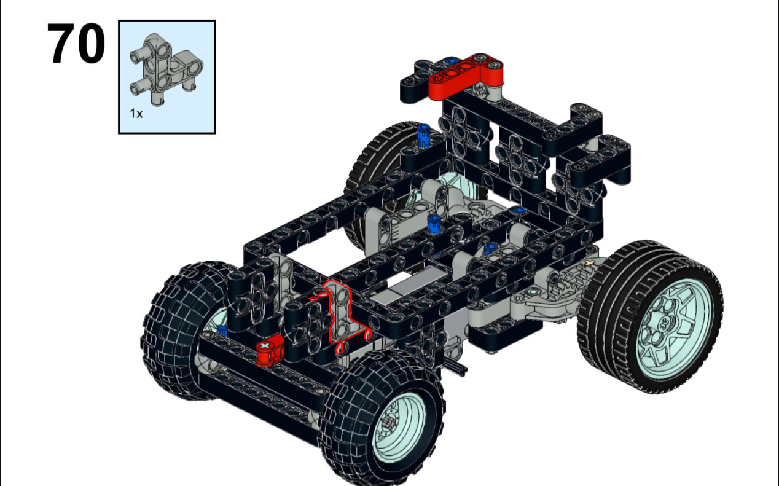
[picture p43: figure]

## B. Steering Mechanism

We use a different type of steering system that is much more efficient and faster, handles much better, and doesn't get stuck

## C. Mechanical Stability and Iterations

The stability of our robot is largely due to our chassis and steering design.

II. POWER ARCHITECTURE AND SENSORS

## A. Power System Design

We use two rechargeable 18650 Li-ion batteries, each with a capacity of 3.7 V and 2,200 mAh, which power the robot and its electronic components.

B.Selection and Justification of Sensors

Our main camera was a DFRobot Husky Lens; we chose it because of its advanced AI system, which simplifies programming and object detection. We used ultrasonic sensors because of their simplicity and compact size.

## C. Weaknesses and Mitigations

When we first started programming our sensors, their extremely high sensitivity caused them to behave erratically and unpredictably; additionally, because the robot was heavier than usual, its speed was reduced.

III. REPRODUCIBILITY AND QUALITY ON GITHUB

## A. Estructura del Repositorio

We have structured our entire GitHub repository very similarly to the teachers', including the following items (as well as 2D and 3D models)

Contents:-Project Overview-Vehicle Photos-Components and Hardware-Mobility-Management-Chassis-Steering System-Movement and Traction System-Differential-Documentation-Power and Sense Management-Power Management-Sense Management-Obstacle Management-WRO 2026 Competition Info.

## B. Summary of the Breeding Guide

The steps would be to build the robot's chassis using the guide in the “Models” section, 3D print the parts, purchase the electronic components, and assemble them (Components and Hardware). Finally, upload the src code.

VI. CONCLUSION

In conclusion, from my perspective, the most important thing for me was committing to completing the challenge, learning new things, and above all, working as a team and thinking outside the box.

Acknowledgments:

The team would like to thank Eduardo Alvarado González for his guidance throughout the season, Normal Superior Moises Sáenz for providing the facilities, and [any sponsors/mentors].

World Robot Olympiad 2026 – Robots Meet CulturePage

WRO Future Engineers 2026 | Technical Engineering Documentation Team: Junior High

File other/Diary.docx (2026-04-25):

Diary

-On November 8, we began building the chassis; we ran into some problems along the way, so we were only able to make a little progress. At that point, we weren’t entirely sure what we were going to build or how we would approach the project, but later on we settled on a clear direction.

-On November 15, while building the chassis, we realized that some parts were broken, while others were not positioned correctly. Our solution was to take it apart to fix several issues.

-On November 29, we began integrating key electronic components into the robot. These included an ultrasonic sensor, a HuskyLens camera developed by DF Robot, and a medium EV3 motor. This stage marked an important step in the development process.

-On March 24, we encountered several difficulties due to a delay in the arrival of an essential component, the printed circuit board (PCB), which limited our ability to move forward. As a result, we had to wait for the part to arrive before continuing with the physical development of the project. During this period, we focused on completing our GitHub page and working on other pending tasks related to the project.

-On April 22, we began developing the 3D design for our robot, named Tymmi. At the same time, we also purchased the Arduino Nano and the printed circuit board (PCB), which marked a significant step forward in the robot’s overall construction and functionality.

-On April 23, we integrated a 3D-printed component into the robot and made further modifications.

-On April 24, we began working on the first part of the video, in which we explain how the system works. During this process, we attempted to complete both the Open Challenge and the Obstacle Challenge. We added some electronic components and the programming.

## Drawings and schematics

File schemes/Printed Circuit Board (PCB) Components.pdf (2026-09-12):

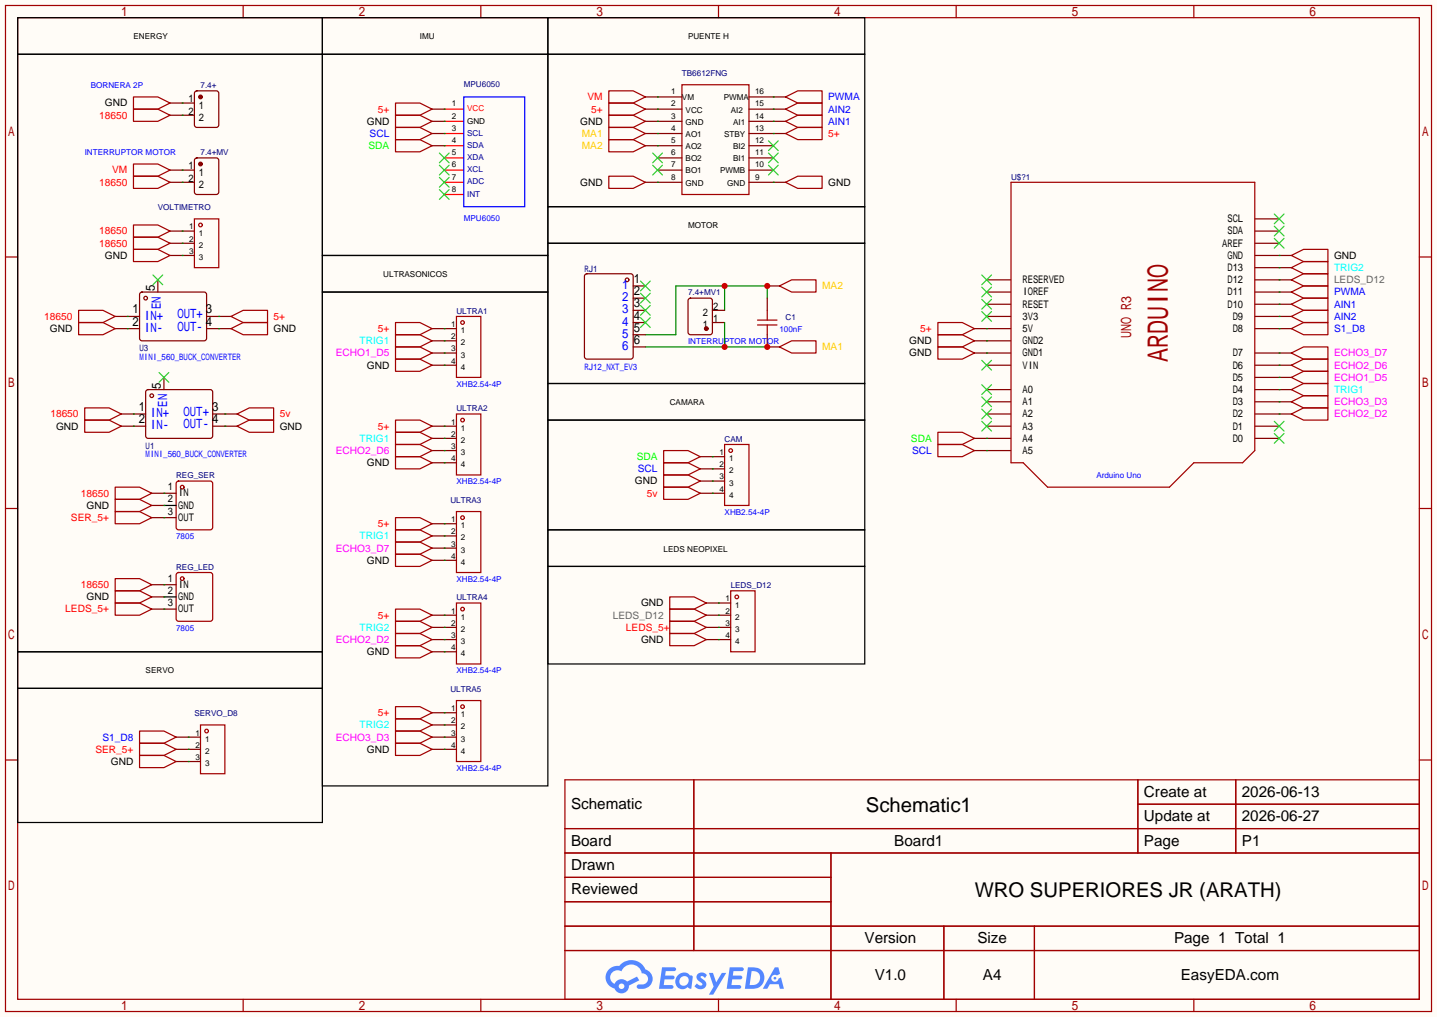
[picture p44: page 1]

Schematic | Schematic1 | Create at | 2026-06-13

Update at | 2026-06-27

Board | Board1 | Page | P1
Drawn | | WRO SUPERIORES JR (ARATH)
Reviewed

Version | Size | Page 1 Total 1
V1.0 | A4 | EasyEDA.com

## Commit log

2026-04-10 Add DC Motor description and image to README
2026-04-10 Add Ultrasonic Sensor and Servomotor to README
2026-04-10 Update README with obstacle challenge and power management
    Added details about traffic signal pillars and clarified power management system.
2026-04-10 Add Ultrasonic HC-SR04 specifications to README
    Added specifications for the Ultrasonic HC-SR04 sensor, including parameters such as operating voltage, current, frequency, and dimensions.
2026-04-11 Add Power Management section to README
    Added a new section on Power Management to the README.
2026-04-11 Add files via upload
    PCB
2026-04-11 Add PCB image to README
    Added PCB image to the README for better visualization.
2026-04-11 Update README.md
    Link EV3 motor
2026-04-11 Update README.md
    Sensor Ultrasonico link
2026-04-11 Update README.md
    servo link
2026-04-11 Fix image links in README for components
    Updated image links for Arduino Nano and HuskyLens DFRobot components.
2026-04-11 Rename WhatsApp Image 2026-04-09 at 3.25.49 PM.jpeg to ultrasonico.jpeg
2026-04-21 Rename WhatsApp Image 2026-04-11 at 12.01.33 PM (2).jpeg to Battery
2026-04-23 Remove entries for 7.4V Buck Converter and Connectors
    Removed descriptions for 7.4V Buck Converter and Connectors and terminals.
2026-04-24 Update README.md
    I corrected the battery model
2026-04-24 Add files via upload
    photo battery
2026-04-24 Update README.md
    I uploaded a photo of the updated battery model
2026-04-24 Update README.md
    I've replaced the regulator model with the correct one and added the correct description and purchase link
2026-04-24 Add files via upload
    Photo regulator
2026-04-24 Update README.md
    I've replaced the photo of the regulator with the correct photo of the current model
2026-04-24 Add files via upload
    New integrated regulator
2026-04-24 Update README.md
    I've replaced the previous battery specifications table with the most recent one and updated the photo
2026-04-24 Update README.md
    I've updated the battery description in “Power Management”
2026-04-24 Adjust image heights in README.md
    Updated image heights for EV3 Medium Motor and Ultrasonic HC-SR04 in README.
2026-04-24 Fix image link for chassis prototype
    Updated image source for the chassis prototype in the README.
2026-04-24 Fix image link for robot prototype section
    Updated image link for the robot prototype in the README.
2026-04-24 Update README.md
    I corrected the error in the titles of “Obstacle Management”
2026-04-25 This is the PCB utiliced for our robot Timmy.
2026-04-26 Enhance README with integration details and instructions
    Updated README with detailed integration and configuration instructions for MindPlus, MPU6050, and OpenMV. Added code snippets and explanations for control logic and wiring.
2026-05-02 Update README with steering system images
    Added images for the steering system in the README.
2026-05-02 Add files via upload
    3D-printed part used in the robot
    [3D model.stl]
2026-05-02 Update README.md
    Link to the official store for the camera used in the robot
2026-09-12 Add files via upload
    PCB schematics
2026-09-16 Add files via upload
    image servo
2026-09-16 Update README.md
    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
2026-09-16 Update README.md
    Information on Edge Case Handling and the Testing & Tuning Process
2026-09-18 Update README.md
    Update on components used; switch from Arduino Nano to Arduino Uno R3
2026-09-18 Update README.md
    Update to the Servomotor Description
2026-09-18 Update README.md
    Updated links to the “Open Challenge” and “Obstacle Challenge” videos
2026-09-18 Update README.md
    Description arduino
2026-09-18 Update README.md
    Wiring Diagram / Electrical Connections
